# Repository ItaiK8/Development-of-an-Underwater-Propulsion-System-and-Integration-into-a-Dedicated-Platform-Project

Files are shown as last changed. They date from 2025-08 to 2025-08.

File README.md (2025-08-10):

# Development-of-an-Underwater-Propulsion-System-and-Integration-into-a-Dedicated-Platform-Project
My Submarine Propulsion System Project for my B.S.c Degree in Mechanical Engineering at Ben-Gurion University

##  Overview
This project documents the **design and manufacturing of a propulsion system** for an autonomous submarine as part of the **HydroCamel initiative** at the Autonomous Marine Robotics Laboratory, Ben-Gurion University of the Negev.  
The goal was to improve the propulsion system’s **pressure tolerance, maintenance accessibility, weight, and cost-efficiency**, while ensuring compatibility with the submarine’s modular design.

---

##  Motivation
Autonomous underwater vehicles (AUVs) are vital tools for research, defense, and industry, enabling underwater inspections, surveys, and sampling without human risk.  
The propulsion system is a critical component, directly affecting maneuverability, endurance, and operational depth.  
This project aimed to replace obsolete, unavailable motors with a **custom, high-performance, pressure-resistant, and maintainable propulsion solution**.

---

##  Objectives
- Design a **motor housing** capable of withstanding **pressures up to 1000 m depth**.
- Ensure **complete watertightness**, low weight, corrosion resistance, and efficient heat dissipation.
- Increase thrust output compared to the existing system.
- Reduce manufacturing costs.
- Ensure adaptability for **different submarine positions** (main thrusters, wing thrusters, directional control).

---

##  Key Features
- **Motor Housing**: Cylindrical dry design, aluminum 6061-T6, selected after comparative analysis with reinforced designs.
- **Motor**: Maxon EC-i 40 brushless DC motor.
- **Seal**: Turcon Roto Variseal dynamic shaft seal.
- **Performance**: Meets thrust and buckling resistance requirements.
- **Standards Compliance**: Verified against relevant international mechanical and marine engineering standards.

---

##  Design Process
1. **Research**: Reviewed previous HydroCamel propulsion designs and relevant marine engineering literature.
2. **Alternatives Evaluation**: Compared multiple housing and sealing concepts based on weight, cost, manufacturability, and performance.
3. **Calculations & Simulations**:
   - Thrust and torque calculations using B-series propeller charts.
   - Strength and buckling analysis (ASME standards).
   - Flow mechanics and environmental condition assessment.
4. **Component Selection**: Based on analytical performance, material properties, and market availability.
5. **CAD & Prototyping**: Developed detailed 3D models and technical drawings for manufacturing.

---

##  Challenges
- Achieving **pressure resistance without overcomplicating design**.
- Delays due to **reserve military duties**.
- Balancing **cost reduction** with **performance requirements**.

---

##  Results
- Final design chosen: **simple, ring-less dry housing** for ease of manufacturing and maintenance.
- Confirmed **adequate thrust** and **structural integrity** for 1000 m operational depth.
- Ready for procurement and assembly phase.

---

##  Technologies & Tools
- **CAD**: SolidWorks
- **Simulation**: Finite Element Analysis (FEA) for strength and buckling
- **Propulsion Analysis**: B-series propeller performance charts
- **Standards**: ASME pressure vessel calculations, ISO 10816 vibration classification
- **Materials**: Aluminum 6061-T6, marine-grade seals

---

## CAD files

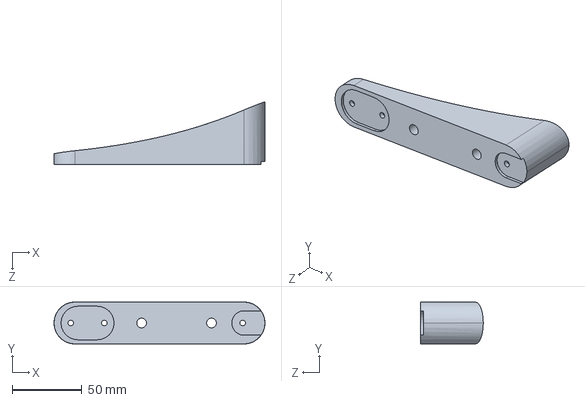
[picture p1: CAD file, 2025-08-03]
Solidworks/Models/Main Motor - Outer Mount - Copy.SLDPRT
151.0 x 30.0 x 44.8 mm

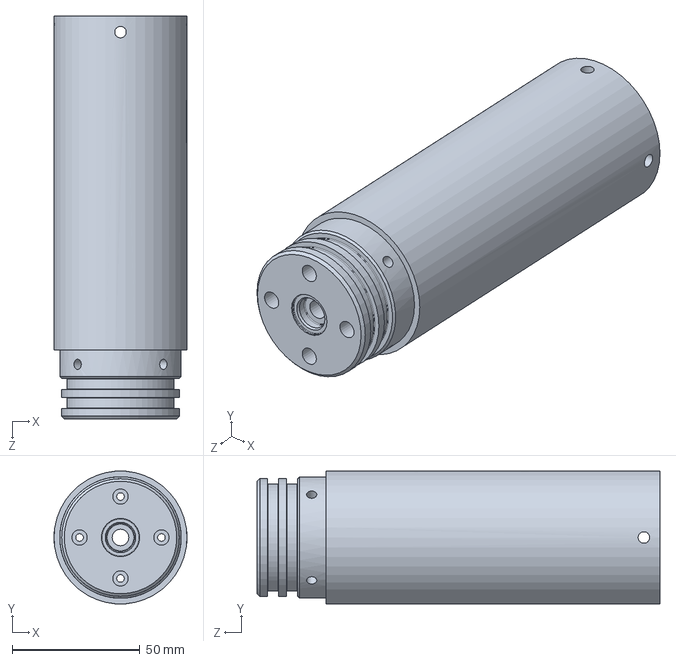
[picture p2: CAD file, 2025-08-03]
Solidworks/Models/Main Body.SLDPRT
52.0 x 52.0 x 157.4 mm

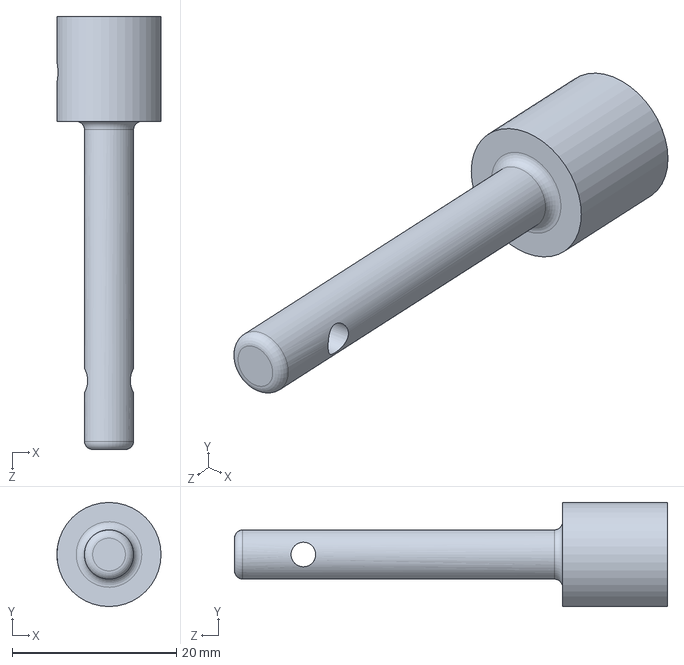
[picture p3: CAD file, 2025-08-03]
Solidworks/Models/Shaft.SLDPRT
12.7 x 12.7 x 52.8 mm

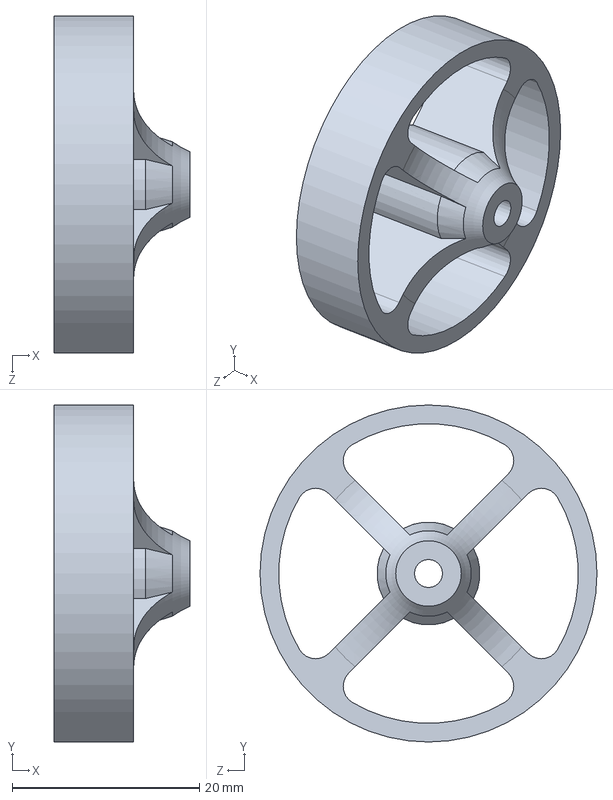
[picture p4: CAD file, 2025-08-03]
Solidworks/Models/Electronic Card Holder.SLDPRT
14.5 x 36.0 x 36.0 mm

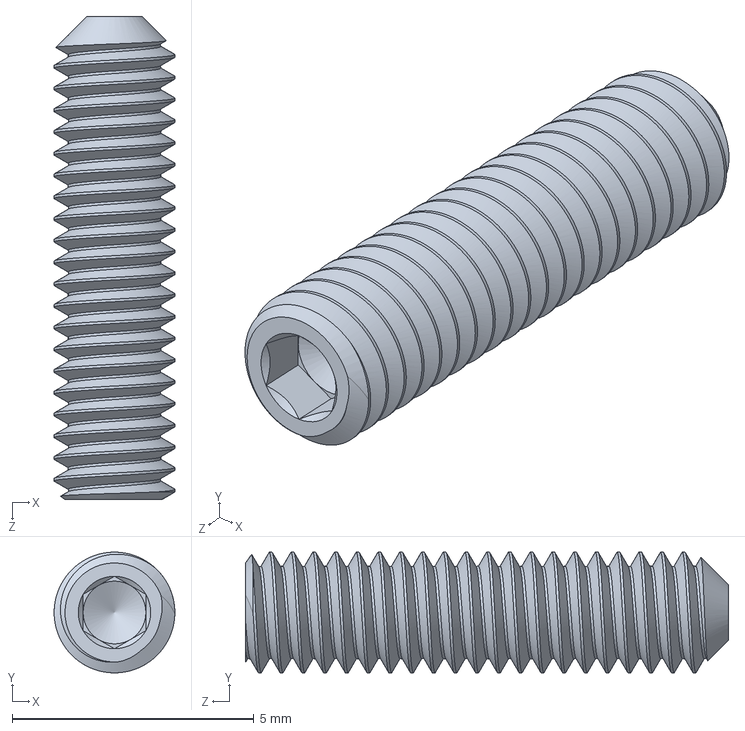
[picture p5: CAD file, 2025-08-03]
Solidworks/Models/M2.5X10_DIN916.SLDPRT
2.50 x 2.50 x 10.0 mm

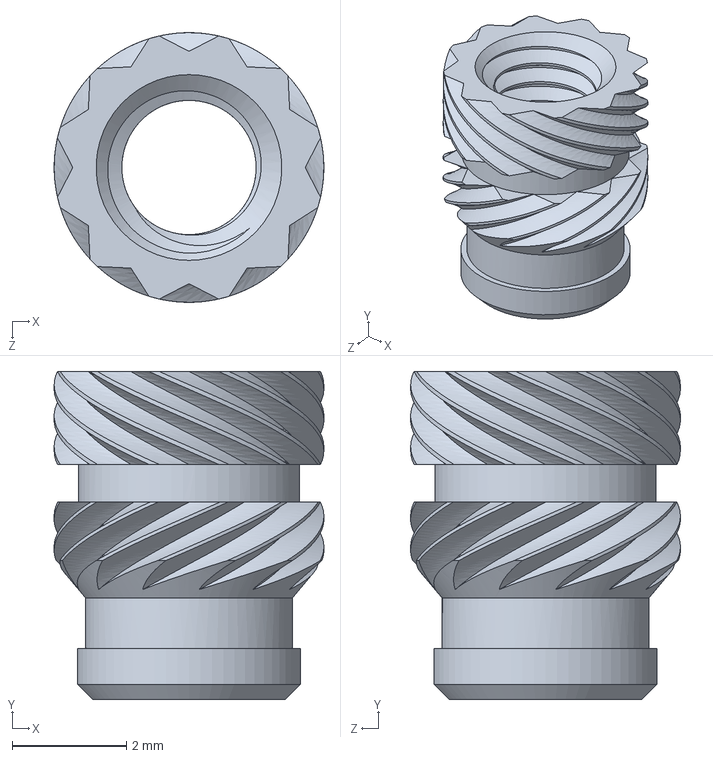
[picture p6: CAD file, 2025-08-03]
Solidworks/Models/Insert M3.SLDPRT
4.72 x 5.74 x 4.72 mm

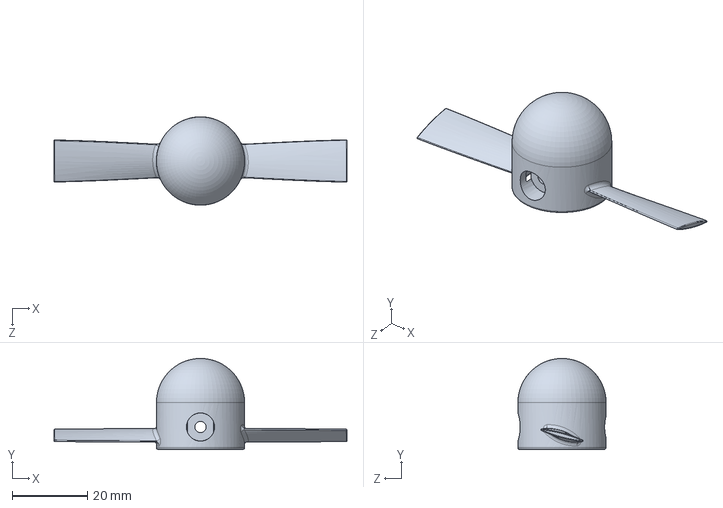
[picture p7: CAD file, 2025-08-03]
Solidworks/Models/Propeller.SLDPRT
78.0 x 24.2 x 23.5 mm

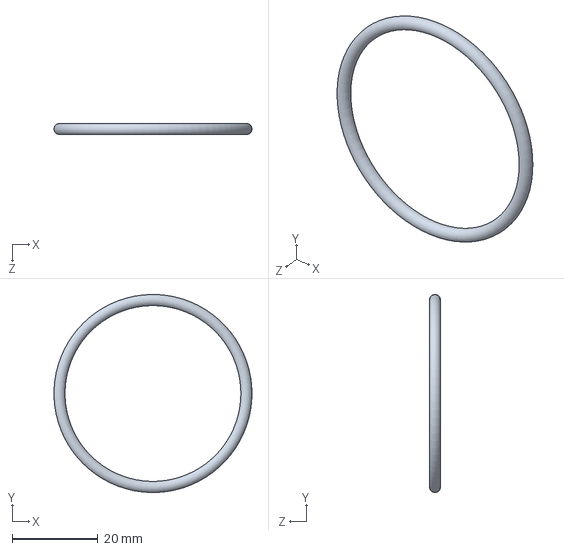
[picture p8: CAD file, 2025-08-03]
Solidworks/Models/O-ring 2-130.SLDPRT
46.2 x 46.2 x 2.60 mm

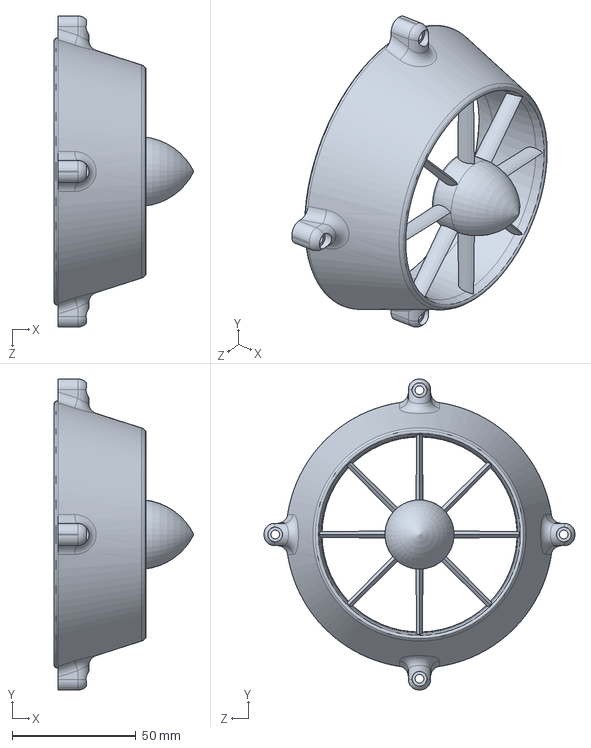
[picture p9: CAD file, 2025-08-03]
Solidworks/Models/Duct.SLDPRT
56.5 x 125.8 x 125.8 mm

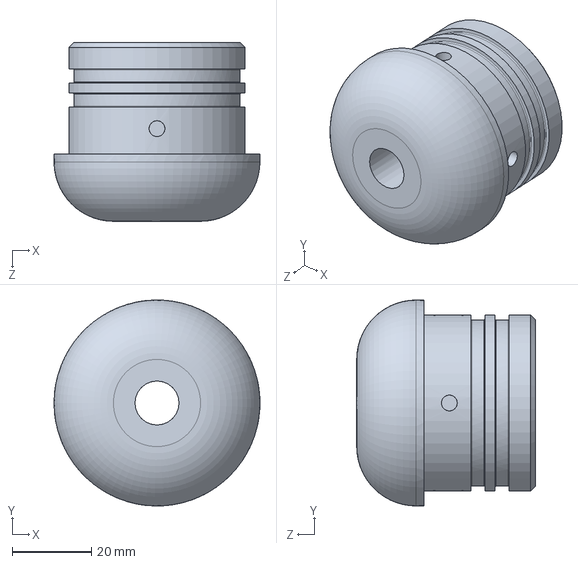
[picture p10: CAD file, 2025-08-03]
Solidworks/Models/Front Cover.SLDPRT
52.0 x 52.0 x 45.1 mm

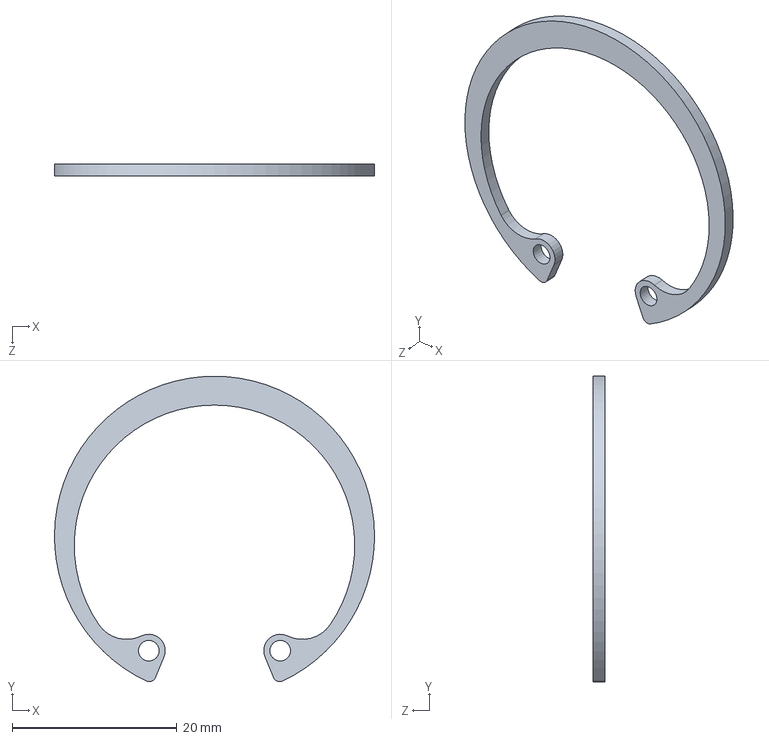
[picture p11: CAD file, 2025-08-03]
Solidworks/Models/Internal Retaining Ring.SLDPRT
38.8 x 37.0 x 1.50 mm

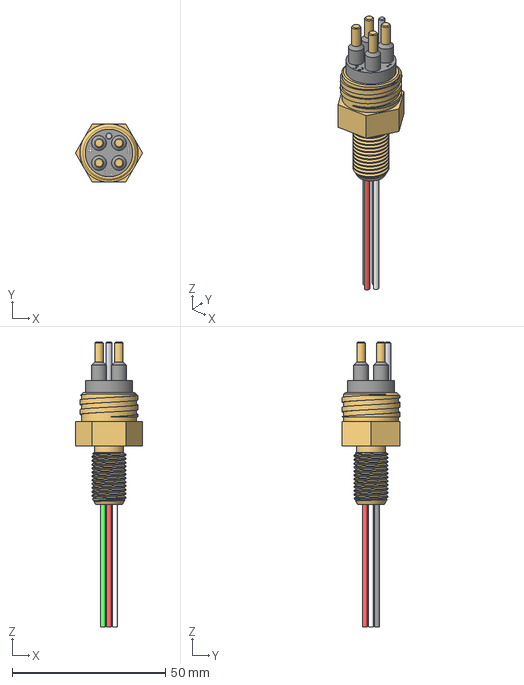
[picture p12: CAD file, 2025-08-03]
Solidworks/Models/mcbh4m.stp
21.9 x 19.0 x 93.0 mm

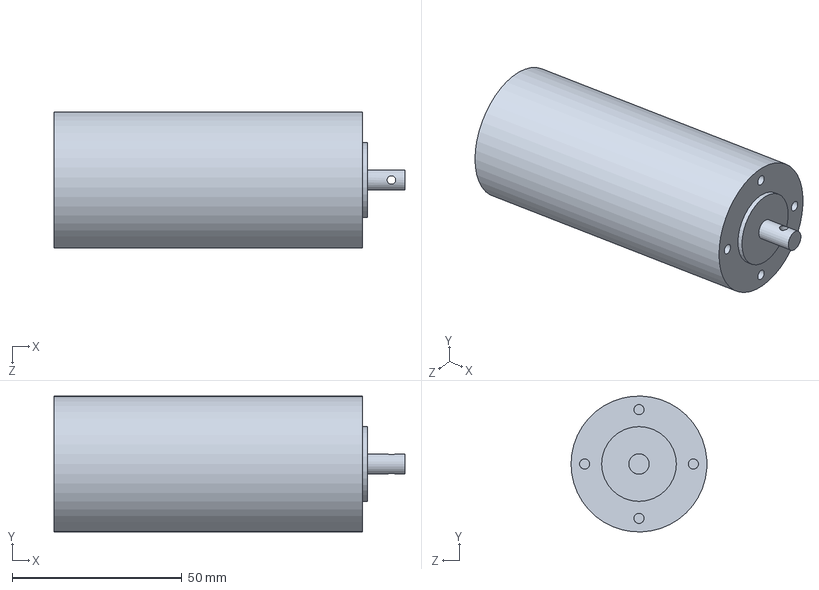
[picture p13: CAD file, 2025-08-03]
Solidworks/Models/Motor EC-i40 Maxon.SLDPRT
103.3 x 40.0 x 40.0 mm

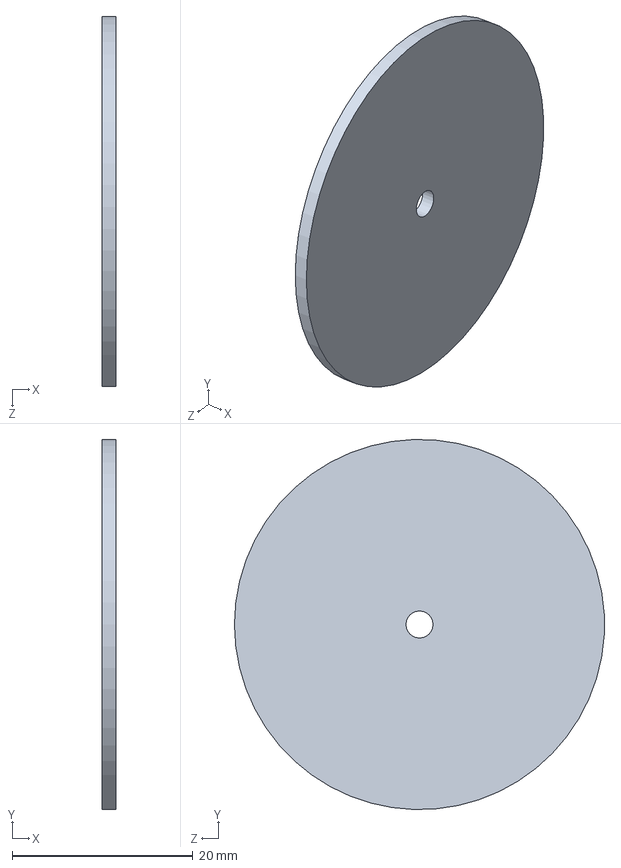
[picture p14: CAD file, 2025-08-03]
Solidworks/Models/Electronic Card.SLDPRT
1.50 x 41.0 x 41.0 mm

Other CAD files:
Solidworks/Models/Front Holder.SLDPRT
Solidworks/Models/M3_DIN125.SLDPRT
Solidworks/Models/M3_DIN985.SLDPRT
Solidworks/Models/O-ring 2-017.SLDPRT
Solidworks/Assembly Drawing/Motor Assembly.SLDDRW
Solidworks/Manufacture Drawings/Back Cover.SLDDRW
Solidworks/Manufacture Drawings/Front Cover.SLDDRW
Solidworks/Manufacture Drawings/Main Body.SLDDRW
Solidworks/Manufacture Drawings/Shaft.SLDDRW
Solidworks/Models/Back Cover.SLDPRT
Solidworks/Models/Back Holder .SLDPRT
Solidworks/Models/Internal Retaining Ring (2).SLDPRT
Solidworks/Models/M3X12_DIN912.SLDPRT
Solidworks/Models/M3X12_ISO7380 (3).SLDPRT
Solidworks/Models/M3X12_ISO7380.SLDPRT
Solidworks/Models/M3X18_DIN912.SLDPRT
Solidworks/Models/M3_DIN125 (2).SLDPRT
Solidworks/Models/M3_DIN985_316 Stainless Steel.SLDPRT
Solidworks/Models/M3__DIN985.SLDPRT
Solidworks/Models/M4X14_DIN_7991_316StainlessSteel.SLDPRT
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

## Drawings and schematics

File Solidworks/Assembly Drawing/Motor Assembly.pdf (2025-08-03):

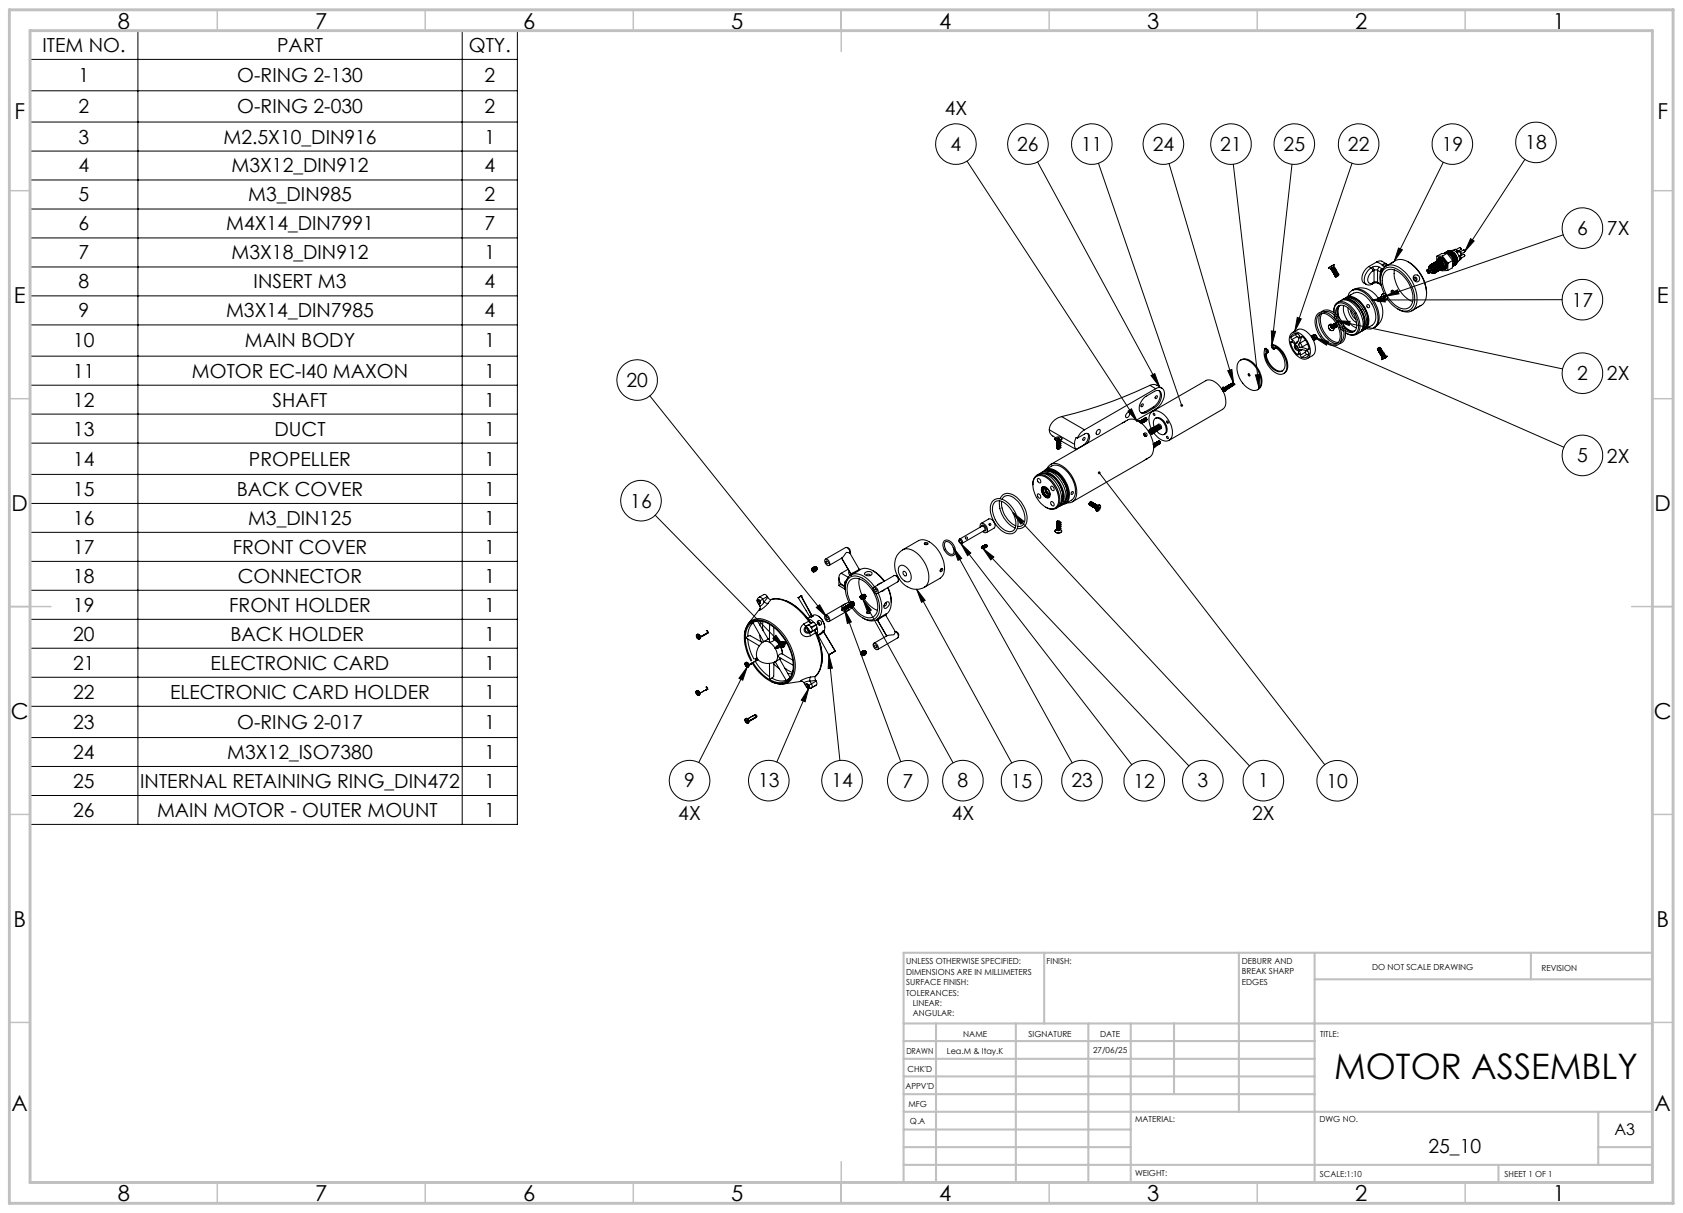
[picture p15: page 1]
FINISH:; DEBURR AND; BREAK SHARP; DO NOT SCALE DRAWING; REVISION; SCALE:1:10; SHEET 1 OF 1

ITEM NO. | PART | QTY.
1 | O-RING 2-130 | 2
2 | O-RING 2-030 | 2
3 | M2.5X10_DIN916 | 1
4 | M3X12_DIN912 | 4
5 | M3_DIN985 | 2
6 | M4X14_DIN7991 | 7
7 | M3X18_DIN912 | 1
8 | INSERT M3 | 4
9 | M3X14_DIN7985 | 4
10 | MAIN BODY | 1
11 | MOTOR EC-I40 MAXON | 1
12 | SHAFT | 1
13 | DUCT | 1
14 | PROPELLER | 1
15 | BACK COVER | 1
16 | M3_DIN125 | 1
17 | FRONT COVER | 1
18 | CONNECTOR | 1
19 | FRONT HOLDER | 1
20 | BACK HOLDER | 1
21 | ELECTRONIC CARD | 1
22 | ELECTRONIC CARD HOLDER | 1
23 | O-RING 2-017 | 1
24 | M3X12_ISO7380 | 1
25 | INTERNAL RETAINING RING_DIN472 | 1
26 | MAIN MOTOR - OUTER MOUNT | 1

UNLESS OTHERWISE SPECIFIED:
DIMENSIONS ARE IN MILLIMETERS
SURFACE FINISH:
TOLERANCES:
LINEAR:
ANGULAR:

NAME | SIGNATURE | DATE | | | | TITLE: MOTOR ASSEMBLY

DRAWN | Lea.M & Itay.K | | 27/06/25

CHK'D
APPV'D
MFG
Q.A | | | | MATERIAL: | DWG NO. 25_10 | A3

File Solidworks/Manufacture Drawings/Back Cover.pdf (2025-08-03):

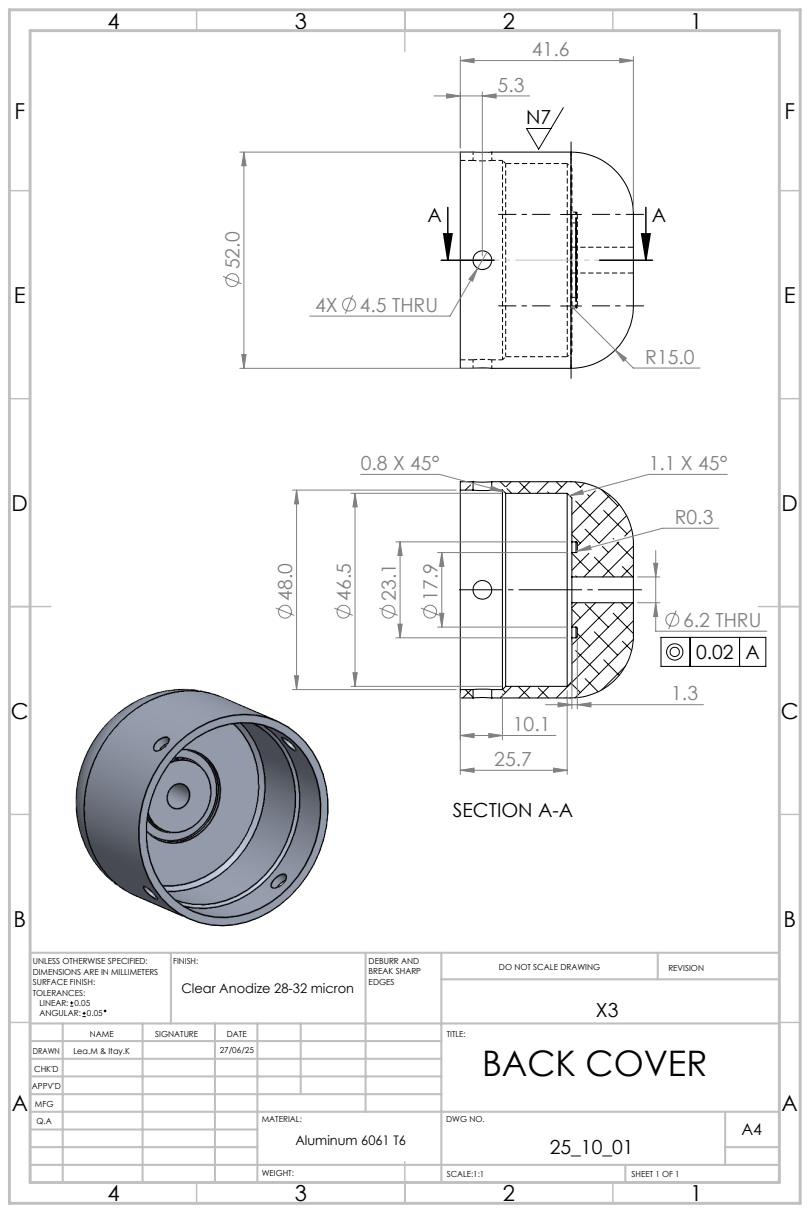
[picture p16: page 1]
4X 4.5 THRU; 6.2 THRU; SECTION A-A; FINISH:; DEBURR AND; BREAK SHARP; DO NOT SCALE DRAWING; REVISION; SCALE:1:1; SHEET 1 OF 1

UNLESS OTHERWISE SPECIFIED:
DIMENSIONS ARE IN MILLIMETERS
SURFACE FINISH:
TOLERANCES:
LINEAR: 0.05
ANGULAR: 0.05

Clear Anodize 28-32 micron

DRAWN | Lea.M & Itay.K | | 27/06/25

NAME | SIGNATURE | DATE | | | | TITLE: BACK COVER

CHK'D
APPV'D
MFG
Q.A | | | | MATERIAL: | DWG NO. 25_10_01 | A4 Aluminum 6061 T6

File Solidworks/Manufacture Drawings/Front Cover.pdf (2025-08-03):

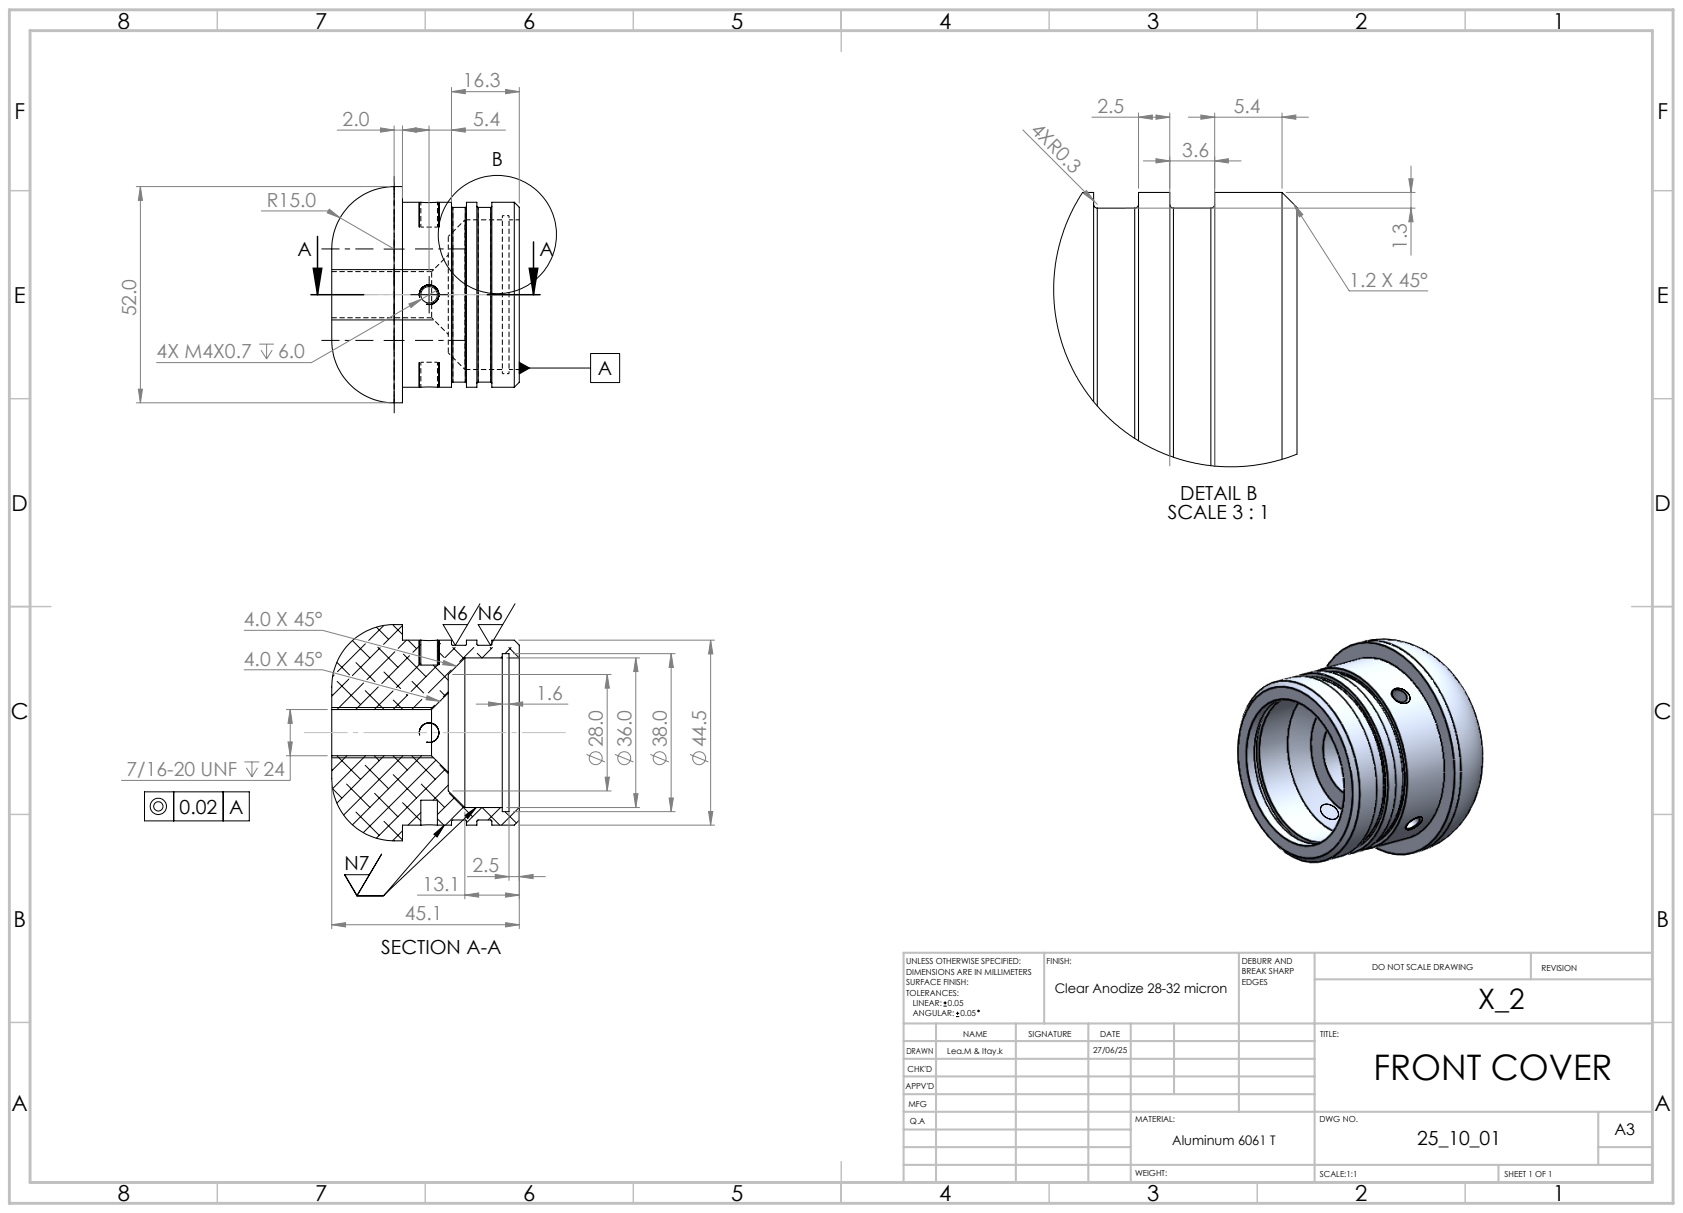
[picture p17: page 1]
7/16-20 UNF 24; SECTION A-A; DETAIL B SCALE 3 : 1; FINISH:; DEBURR AND; BREAK SHARP; DO NOT SCALE DRAWING; REVISION; SCALE:1:1; SHEET 1 OF 1

UNLESS OTHERWISE SPECIFIED:
DIMENSIONS ARE IN MILLIMETERS
SURFACE FINISH:
TOLERANCES:
LINEAR: 0.05
ANGULAR: 0.05

Clear Anodize 28-32 micron

NAME | SIGNATURE | DATE | | | | TITLE: FRONT COVER

DRAWN | Lea.M & Itay.k | | 27/06/25
CHK'D
APPV'D
MFG
Q.A | | | | MATERIAL: | DWG NO. 25_10_01 | A3 Aluminum 6061 T

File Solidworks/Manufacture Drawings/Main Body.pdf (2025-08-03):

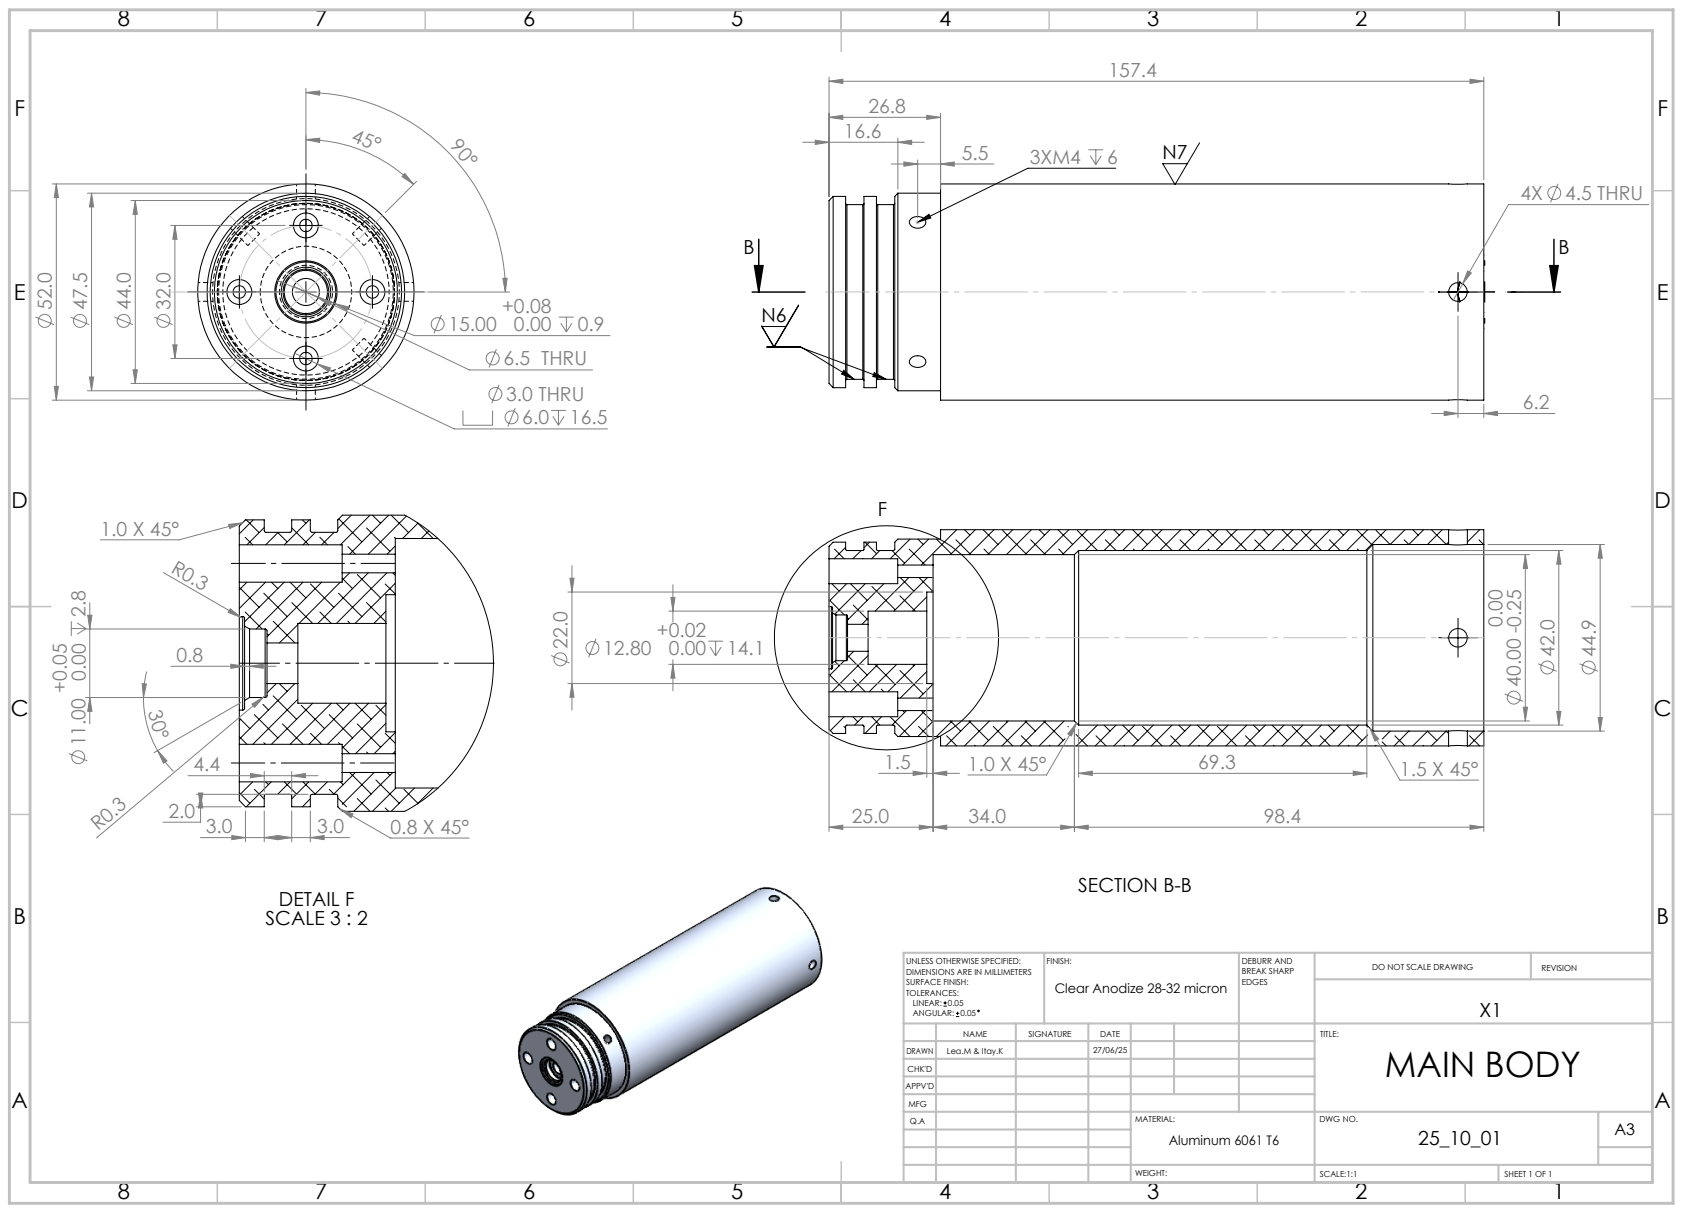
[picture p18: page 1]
4X 4.5 THRU; 0.00 0.9 6.5 THRU 3.0 THRU 6.0 16.5; DETAIL F SCALE 3 : 2; SCALE:1:1; SHEET 1 OF 1

SECTION B-B

UNLESS OTHERWISE SPECIFIED: DIMENSIONS ARE IN MILLIMETERS SURFACE FINISH: TOLERANCES: LINEAR: 0.05 ANGULAR: 0.05 | FINISH: Clear Anodize 28-32 micron | DEBURR AND BREAK SHARP EDGES | DO NOT SCALE DRAWING | REVISION

NAME | SIGNATURE | DATE | | | | TITLE: MAIN BODY

DRAWN | Lea.M & Itay.K | | 27/06/25

CHK'D
APPV'D
MFG
Q.A | | | | MATERIAL: | DWG NO. 25_10_01 | A3 Aluminum 6061 T6

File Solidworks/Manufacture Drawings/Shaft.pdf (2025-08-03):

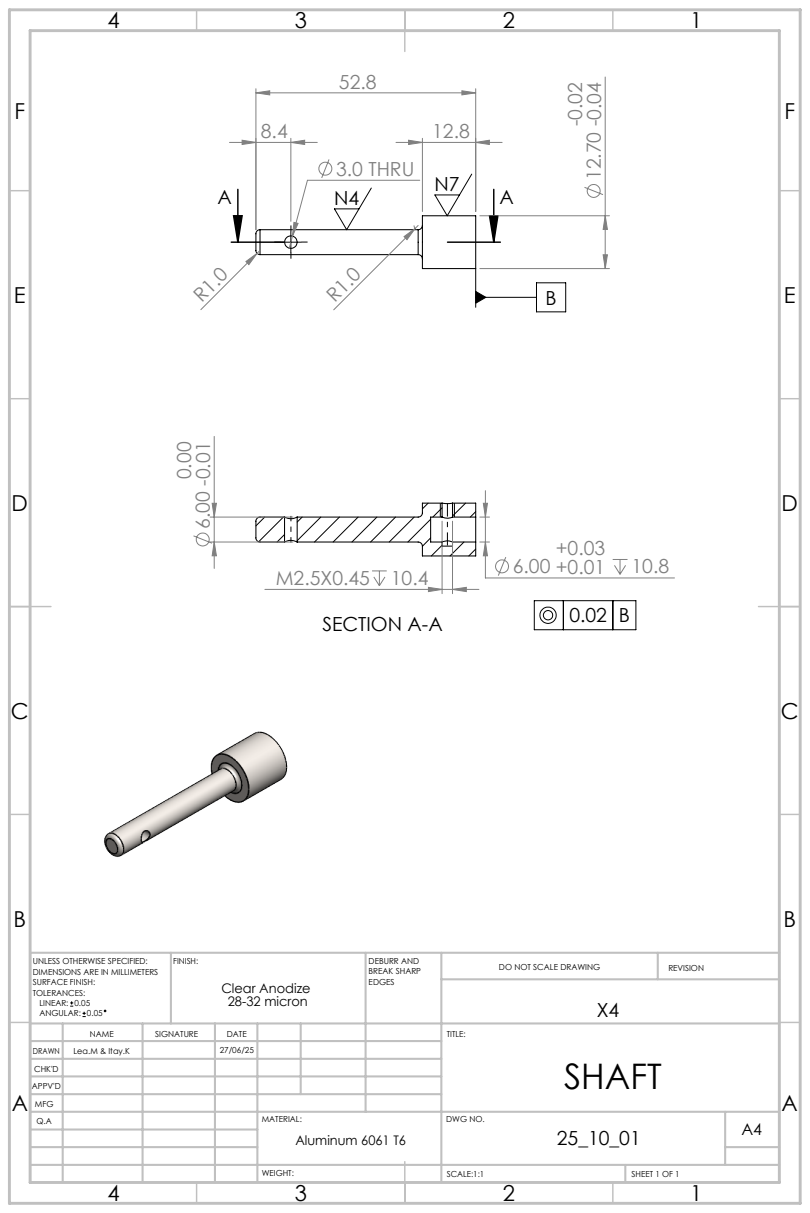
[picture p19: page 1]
3.0 THRU; SECTION A-A; FINISH:; DEBURR AND; BREAK SHARP; DO NOT SCALE DRAWING; REVISION; SCALE:1:1; SHEET 1 OF 1; Clear Anodize 28-32 micron

UNLESS OTHERWISE SPECIFIED:
DIMENSIONS ARE IN MILLIMETERS
SURFACE FINISH:
TOLERANCES:
LINEAR: 0.05
ANGULAR: 0.05

NAME | SIGNATURE | DATE | | | | TITLE: SHAFT

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
